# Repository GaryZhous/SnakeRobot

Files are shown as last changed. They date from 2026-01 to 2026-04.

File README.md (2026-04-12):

# 🐍 SnakeRobot

A snake robot built on the **ESP32** microcontroller. Eight servo motors create a sinusoidal traveling-wave gait, controlled via Bluetooth from a Python GUI that supports manual D-pad steering, autonomous direction tracking, and autonomous position control — with live telemetry (heading, X, Y) streamed back from an onboard IMU and optical-flow sensor.

Demo Video - [Google Drive Link](https://drive.google.com/file/d/18MDr4CC4aUVm_WDjIK8m0Mhruf4S-zMb/view?usp=sharing)

---

## Table of Contents
- [Design Fair Poster](#design-fair-poster)
- [Demo / Pinout](#demo--pinout)
- [How It Works](#how-it-works)
- [Hardware Setup](#hardware-setup)
- [Software Setup](#software-setup)
- [Bluetooth Commands](#bluetooth-commands)
- [Python GUI](#python-gui)
- [Camera Web Server](#camera-web-server)
- [3D Printing](#3d-printing)
- [Project Structure](#project-structure)

---

## Design Fair Poster

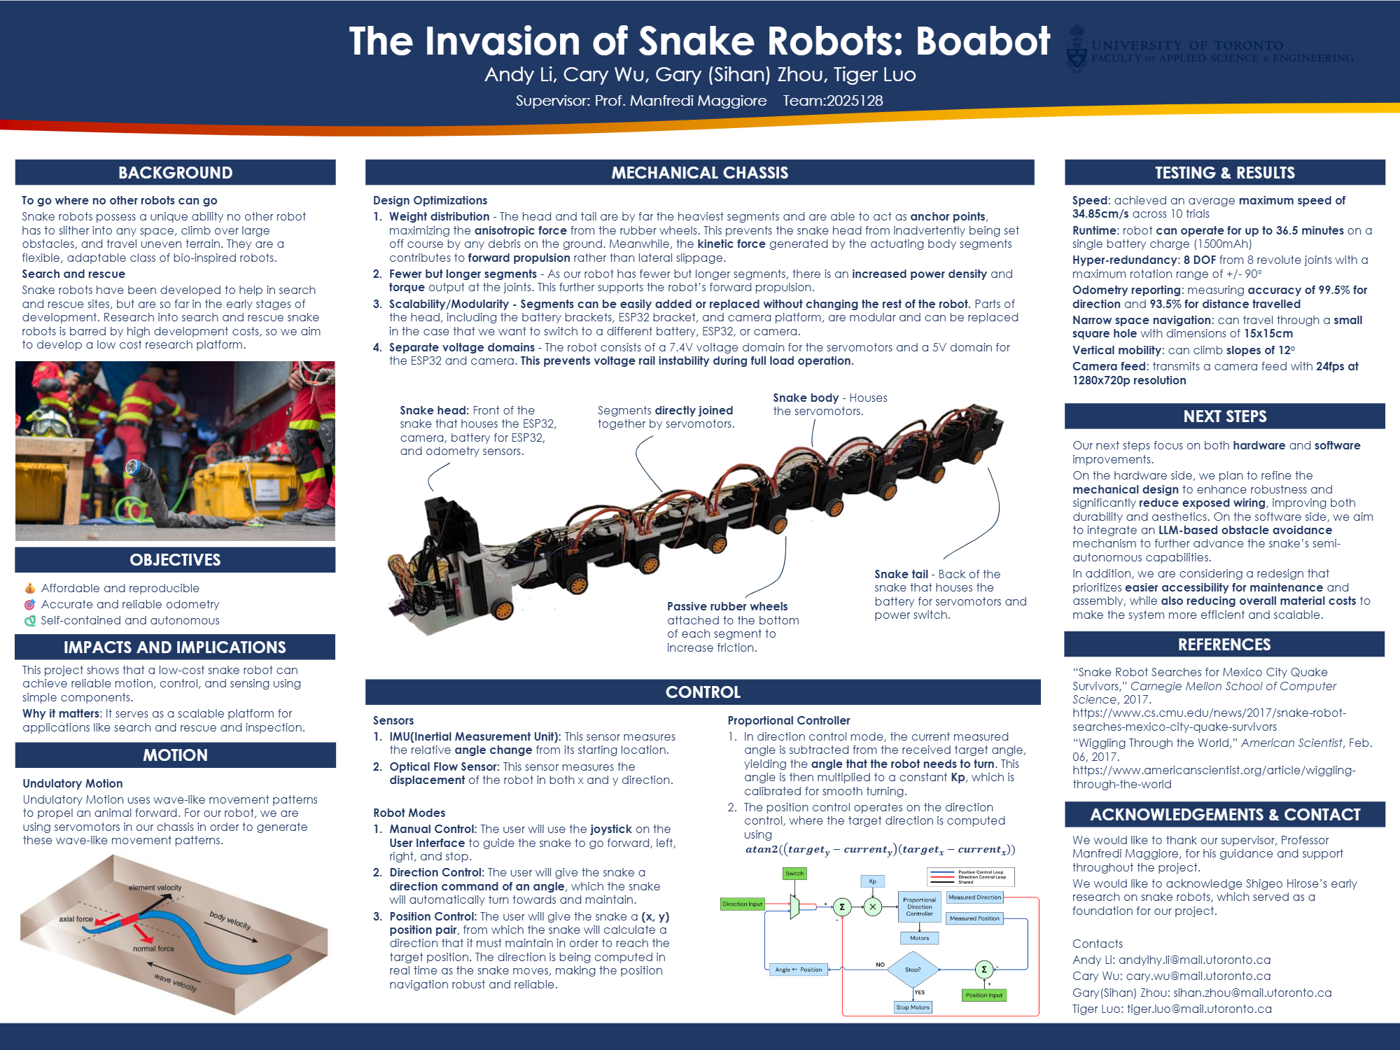
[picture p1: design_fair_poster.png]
Design Fair


The poster provides a high-level overview of the project — motivation, system architecture, hardware components, control strategy, and results — as presented at the UofT Electrical and Computer Engineering Undergraduate Capstone Design Fair on March 26, 2026.

---

## Demo / Pinout

ESP32 pinout reference

---

## How It Works

Each joint of the snake is driven by a servo. The firmware generates a **sinusoidal traveling wave** across all eight joints:

```
angle_i(t) = center + turnOffset + amplitude × sin(2π × frequency × t + i × 2π/8)
```

- **Frequency** is fixed at 0.5 Hz (one full undulation every 2 seconds).
- **Amplitude** (0 – 60 °) controls how wide each swing is — higher = faster forward motion.
- **Turn offset** shifts the neutral position of all joints together, steering the robot left or right.
- Both amplitude and turn offset are **slew-rate limited** so changes are smooth, not jerky.

The ESP32 reads heading from a **BNO08x IMU** and displacement from a **PMW3901 optical-flow sensor**, fusing them into world-frame odometry. This telemetry (heading, X position, Y position) is streamed back as packed `float32` frames so the Python GUI can display live position data and close a control loop.

---

## Hardware Setup

### Parts
| Qty | Component |
|-----|---|
| 1 | ESP32 development board |
| 8 | Servo motors (standard 5 V hobby servos) |
| 1 | BNO08x IMU (SPI) |
| 1 | Bitcraze PMW3901 optical-flow sensor (SPI) |
| 1 | 5 V regulated power supply (servos draw significant current) |
| — | Jumper wires, chassis / 3-D printed links (see [3D Printing](#3d-printing)) |

### Wiring

| Servo # | ESP32 GPIO |
|---|---|
| 1 | 13 |
| 2 | 12 |
| 3 | 14 |
| 4 | 27 |
| 5 | 26 |
| 6 | 25 |
| 7 | 33 |
| 8 | 32 |

| Sensor | Signal | ESP32 GPIO |
|---|---|---|
| BNO08x | CS | 15 |
| BNO08x | INT | 22 |
| BNO08x | RESET | 4 |
| PMW3901 | CS | 5 |
| Both | SCK / MISO / MOSI | 18 / 19 / 23 |

> **Tip:** Power the servos from a dedicated 5 V rail, **not** directly from the ESP32's 3.3 V pin. Share a common ground between the servo power supply and the ESP32.

### Motor Calibration
Before running the snake gait, make sure each servo is centered at 90 °:

1. Flash the `Calibration_Serial` sketch and open the Serial Monitor.
2. The sketch drives all servos to 90 ° sequentially so you can verify each joint.
3. Physically adjust the servo horns / linkages so the robot is straight.
4. Flash the main firmware and send `c` over Bluetooth to re-center before motion.

---

## Software Setup

### ESP32 Firmware

1. Install the **Arduino IDE** and add the ESP32 board package:  
   `https://raw.githubusercontent.com/espressif/arduino-esp32/gh-pages/package_esp32_index.json`
2. Install the following libraries via the Arduino Library Manager:
   - **ESP32Servo**
   - **Adafruit BNO08x** (IMU)
   - **Bitcraze PMW3901** (optical flow)
3. Open `ESP32/6_Position_Control_Avg_Yaw/` (the latest version) in the Arduino IDE, select your ESP32 board and COM port, then upload.

### Python GUI

Requires **Python 3.7+** and a Bluetooth-paired serial port.

```bash
pip install pyserial
# tkinter ships with most Python distributions; if missing:
# Ubuntu/Debian: sudo apt-get install python3-tk
# Windows/macOS: included in the standard Python installer
```

Pair your PC with the ESP32 Bluetooth device named **`ESP32_Snake`**, note the assigned COM port (e.g. `COM11` on Windows, `/dev/rfcomm0` on Linux), then edit the `PORT` constant at the top of `bluetooth.py`.

---

## Bluetooth Commands

All commands are sent as **exactly 8 ASCII bytes** over the Bluetooth SPP link (1 character header + 7 zero-padding bytes, e.g. `"l0000000"`).

### Mode markers
| Command | Action |
|---|---|
| `M0000000` | Switch to **Manual** mode |
| `D0000000` | Switch to **Direction** auto-control (tracks a target heading) |
| `P0000000` | Switch to **Position** auto-control (tracks target X/Y coordinates) |

### Motion commands (Manual mode)
| Key / Command | Action |
|---|---|
| `s` | Go **straight** — reset turn offset to 0 and resume motion |
| `l` | Turn **left** (smooth) |
| `r` | Turn **right** (smooth) |
| `c` | **Calibrate** — move all servos to 90 ° and stop motion |
| `0` – `9` | Set amplitude to `digit × 5` degrees (0 – 45 °) |
| `+` | Increase amplitude by 5 ° (up to 60 °) |
| `-` | Decrease amplitude by 5 ° |

### Auto-control payloads
| Format | Mode | Meaning |
|---|---|---|
| `+1200000` / `-0900000` | Direction | Target heading angle in degrees (signed, 8 chars) |
| `+100+200` | Position | Target X and Y position in cm (signed 3-digit each) |

---

## Python GUI

### `bluetooth.py` — Full Control Panel

- Connects to the ESP32 over a Bluetooth SPP serial port.
- Displays live **direction (°)**, **X position**, and **Y position** from the telemetry stream.
- **D-pad** for manual steering with drag support, auto-repeat, and analog angle input (−15 ° … +15 °).
- **Amplitude ±** buttons with a live display (range 0 – 60 °).
- **Mode selector** with three modes:
  - **Manual** — direct D-pad / key control.
  - **Direction** (auto) — enter a target heading; the robot steers to match it.
  - **Position** (auto) — enter target X/Y coordinates; the robot navigates to them.

**Running the script:**
```bash
python bluetooth.py
```

---

## Camera Web Server

The `CameraWebServer/` folder contains an **ESP32-CAM** sketch that streams live video over Wi-Fi.

### Setup
1. Open `CameraWebServer/CameraWebServer.ino` in the Arduino IDE.
2. Edit the `ssid` and `password` constants at the top of the file to match your Wi-Fi network.
3. Select the correct camera model by editing `board_config.h`.
4. Upload to an ESP32-CAM module.
5. Open the Serial Monitor at 115200 baud — after connecting the camera prints its local IP address.
6. Navigate to `http://<IP>` in a browser to view the live stream and camera controls.

---

## 3D Printing

The `CAD Files/` directory contains all STL meshes used to print the robot chassis, and the `3D Print Files/` directory contains pre-sliced Cura `.3mf` files ready to send directly to a printer.

### CAD Files (STL)

| File | Description |
|---|---|
| `Assembled.stl` | Full snake assembly reference |
| `AssembledHead.stl` / `AssembledTail.stl` | Head and tail sub-assemblies |
| `Head.stl` / `Tail.stl` | Individual head and tail prints |
| `Connecting Piece.stl` | Body links that join servo segments |
| `Motor Wrap.stl` | Servo motor sleeve / housing |
| `MG996R SBORKA.stl` | MG996R servo bracket assembly |
| `Clamp.stl` | Clamping ring for segment joints |
| `ESPBracket.stl` | ESP32 board mounting bracket |
| `ESP-WROOM32.stl` | ESP32 module reference model |
| `IMU.stl` | BNO08x IMU mounting housing |
| `Optical Flow Senssor.stl` | PMW3901 optical-flow sensor mount |
| `Battery.stl` / `BatteryBracket.stl` / `BatteryHead.stl` / `Battery Compartment.stl` | Battery enclosure and mounting hardware |
| `CamCaseTop.stl` / `CamCase Bottom.stl` | ESP32-CAM enclosure |
| `CameraPlatform 2.stl` | Camera platform for top-down mounting |

### 3D Print Files (pre-sliced)

Ready-to-print Cura `.3mf` files for **PLA** at standard settings:

| File | Contents |
|---|---|
| `Rev3 Segment.gcode.3mf` | Snake body link segments |
| `Rev3 Brackets PLA.gcode.3mf` | Servo mounting brackets |
| `Rev3 Head PLA.gcode.3mf` | Head section |
| `Rev3 Tail PLA.gcode.3mf` | Tail section |
| `Rev3 BatteryBracket PLA.gcode.3mf` | Battery bracket |
| `Rev3 CameraPlatform PLA.gcode.3mf` | Camera platform |
| `Servo Base Plate (1).gcode.3mf` | Servo base plate |

> **Tip:** Open `.3mf` files in [Ultimaker Cura](https://ultimaker.com/software/ultimaker-cura/) (or any slicer that supports `.3mf`) to preview or adjust print settings before slicing.

---

## Project Structure

```
SnakeRobot/
├── Team128_Design_Fair_Poster.pdf         # Design fair poster
├── Arduino/
│   └── Test_Code_250902/              # Early 2-servo Arduino prototype
├── CAD Files/                         # STL meshes for all printed parts
│   ├── Assembled.stl                  # Full snake assembly reference
│   ├── Head.stl / Tail.stl
│   ├── Connecting Piece.stl
│   ├── Motor Wrap.stl
│   ├── ESPBracket.stl
│   ├── IMU.stl / Optical Flow Senssor.stl
│   ├── Battery Compartment.stl / Battery.stl / ...
│   └── CamCaseTop.stl / CamCase Bottom.stl / ...
├── 3D Print Files/                    # Pre-sliced Cura .3mf files (PLA)
│   ├── Rev3 Segment.gcode.3mf
│   ├── Rev3 Brackets PLA.gcode.3mf
│   ├── Rev3 Head PLA.gcode.3mf
│   ├── Rev3 Tail PLA.gcode.3mf
│   ├── Rev3 BatteryBracket PLA.gcode.3mf
│   ├── Rev3 CameraPlatform PLA.gcode.3mf
│   └── Servo Base Plate (1).gcode.3mf
├── CameraWebServer/                   # ESP32-CAM Wi-Fi video stream server
│   ├── CameraWebServer.ino
│   ├── board_config.h
│   ├── camera_pins.h
│   └── ...
├── ESP32/
│   ├── Manual_Control_SerialBT/       # Basic manual Bluetooth control
│   ├── 1_Sensors_with_Manual_Control/
│   ├── 2_Sensors_with_Manual_Control_with_bluetooth_send_receive/
│   ├── 3_Proportional_control/        # Proportional steering controller
│   ├── 4_Analog_Manual/               # Analog angle steering via Bluetooth
│   ├── 5_Analog_Manual_Position_Control/  # Analog steering + position control
│   ├── 6_Position_Control_Avg_Yaw/    # ← Latest firmware (use this one)
│   ├── Calibration/                   # Servo calibration sketch
│   ├── Calibration_Serial/            # Serial-assisted servo calibration
│   ├── Tiger_avg_yaw/                 # Alternate position-control variant
│   ├── Test_Code_251028/
│   ├── Test_Code_251118.ino
│   ├── Test_Code_251130.cpp
│   ├── Test_Code_251202.cpp
│   ├── Test_Code_260109.cpp
│   ├── Test_Code_260114.cpp
│   ├── Test_Code_260119/              # Sensor integration test sketch
│   └── Test_Code_260119.cpp
├── bluetooth.py                       # Full-featured Python control GUI
└── README.md
```

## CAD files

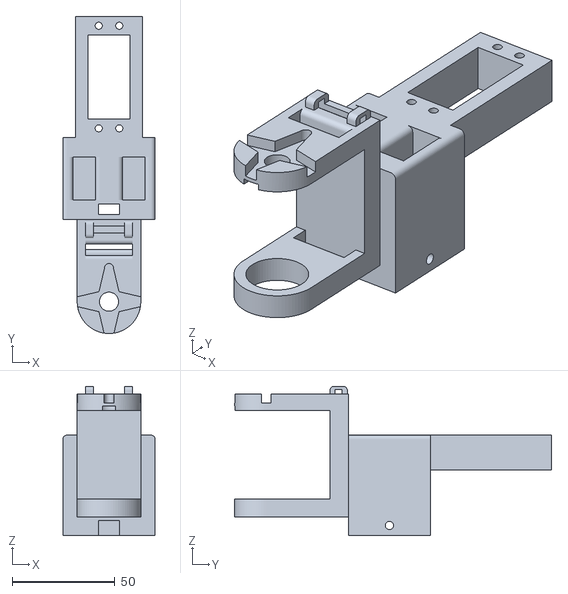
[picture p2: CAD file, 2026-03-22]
CAD Files/Assembled.stl
45.0 x 154.5 x 72.8

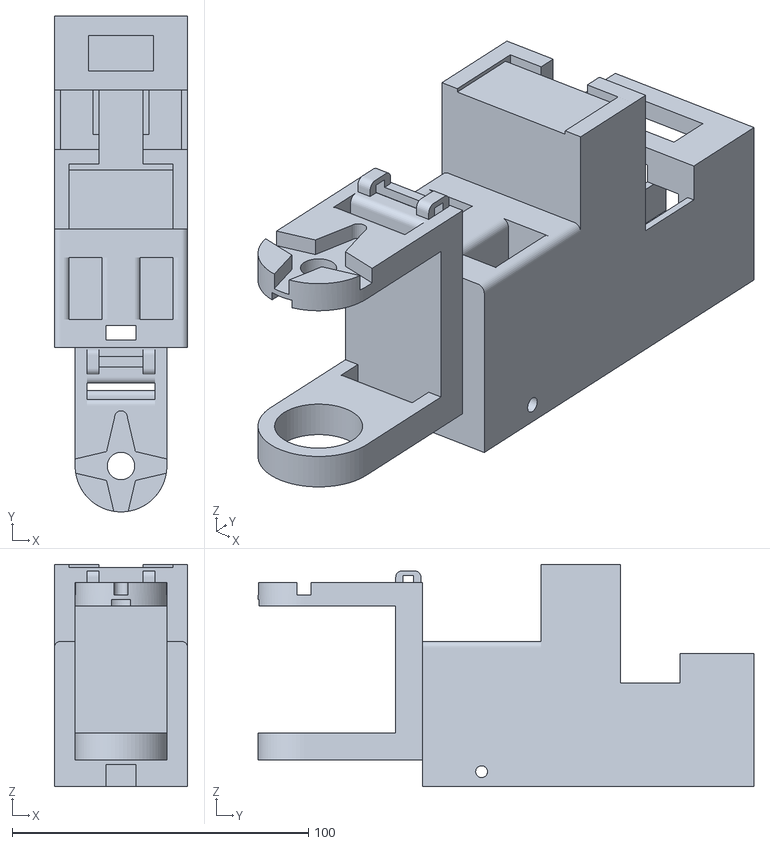
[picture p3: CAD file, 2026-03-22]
CAD Files/AssembledTail.stl
45.0 x 167.5 x 75.0

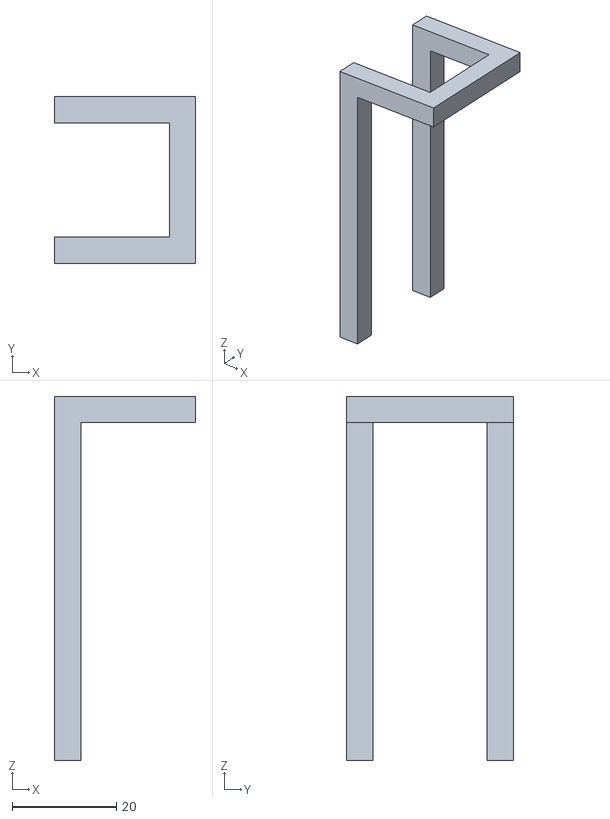
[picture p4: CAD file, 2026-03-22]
CAD Files/BatteryBracket.stl
27.1 x 32.1 x 70.0

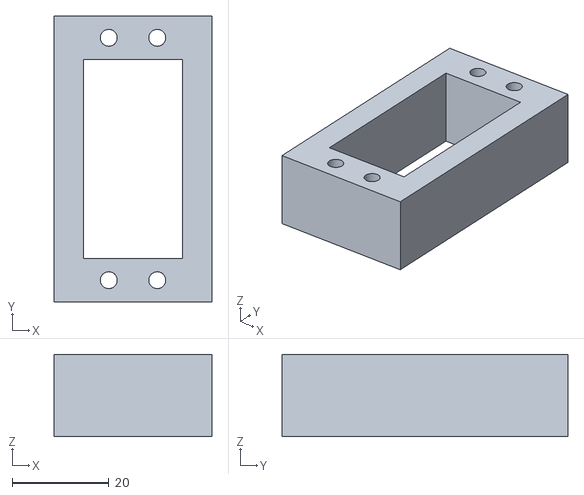
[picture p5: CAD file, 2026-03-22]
CAD Files/Motor Wrap.stl
32.5 x 59.0 x 17.0

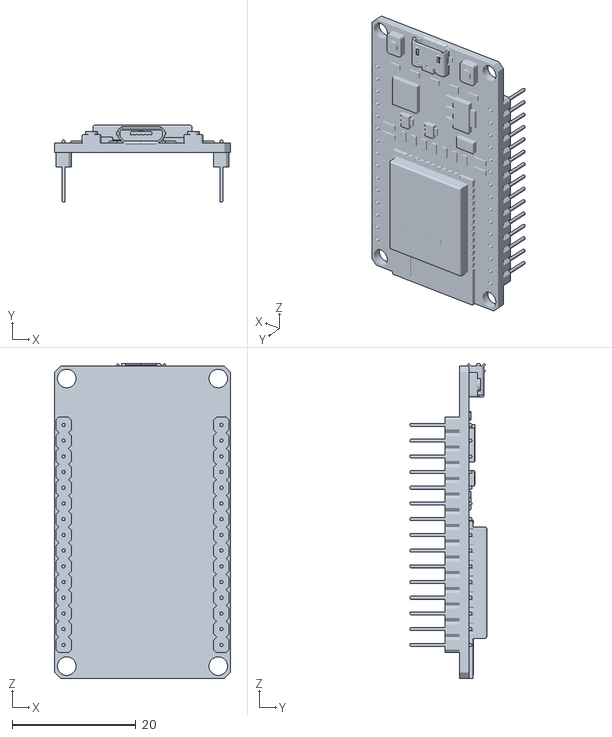
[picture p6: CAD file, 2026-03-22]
CAD Files/ESP-WROOM32.stl
28.5 x 12.4 x 50.9

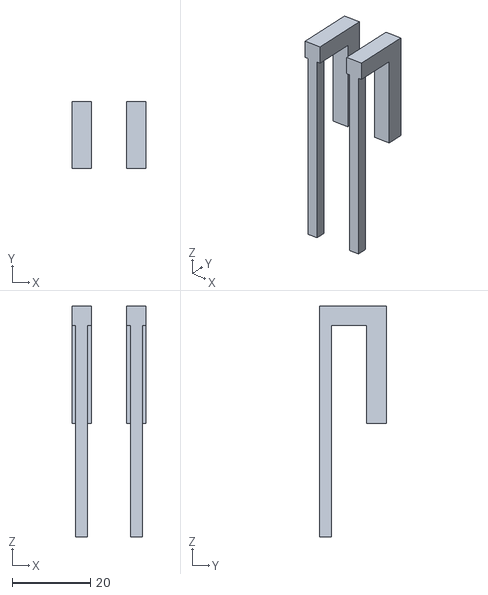
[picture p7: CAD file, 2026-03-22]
CAD Files/ESPBracket.stl
19.0 x 17.0 x 59.0

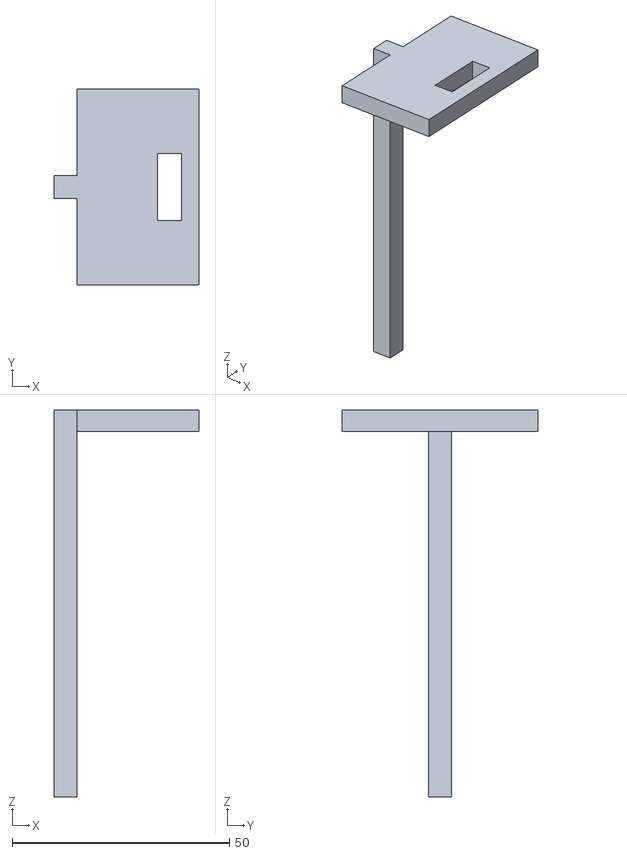
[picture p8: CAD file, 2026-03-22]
CAD Files/CameraPlatform 2.stl
33.3 x 45.0 x 89.0

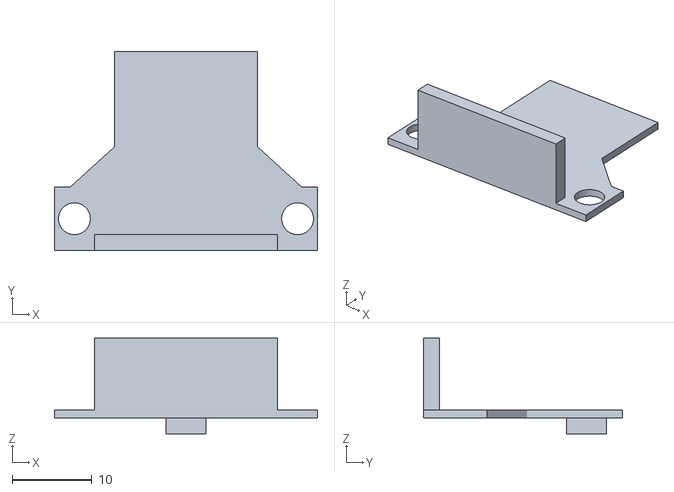
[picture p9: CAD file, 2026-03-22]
CAD Files/Optical Flow Senssor.stl
33.0 x 25.0 x 12.0

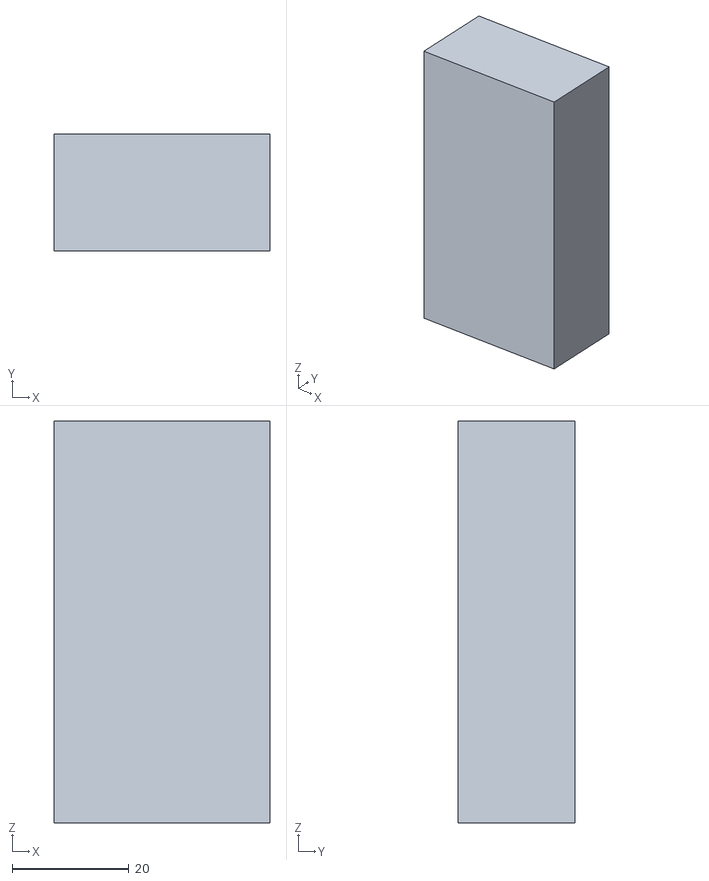
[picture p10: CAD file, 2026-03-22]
CAD Files/Battery.stl
37.0 x 20.0 x 69.0

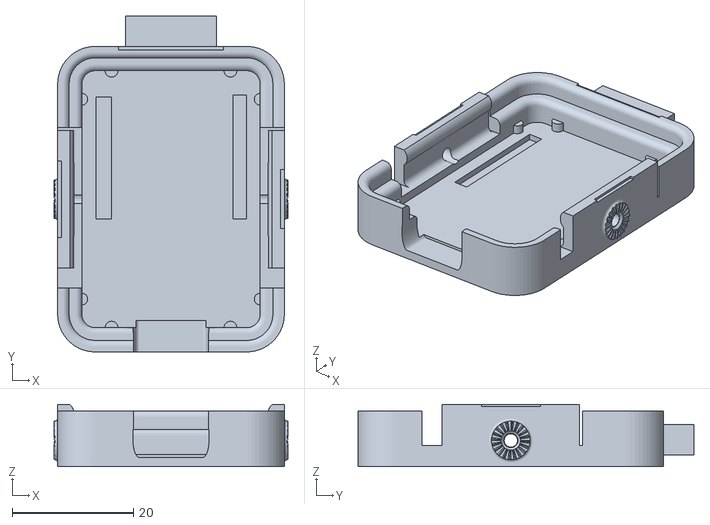
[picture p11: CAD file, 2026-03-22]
CAD Files/CamCase Bottom.stl
38.6 x 55.4 x 10.3

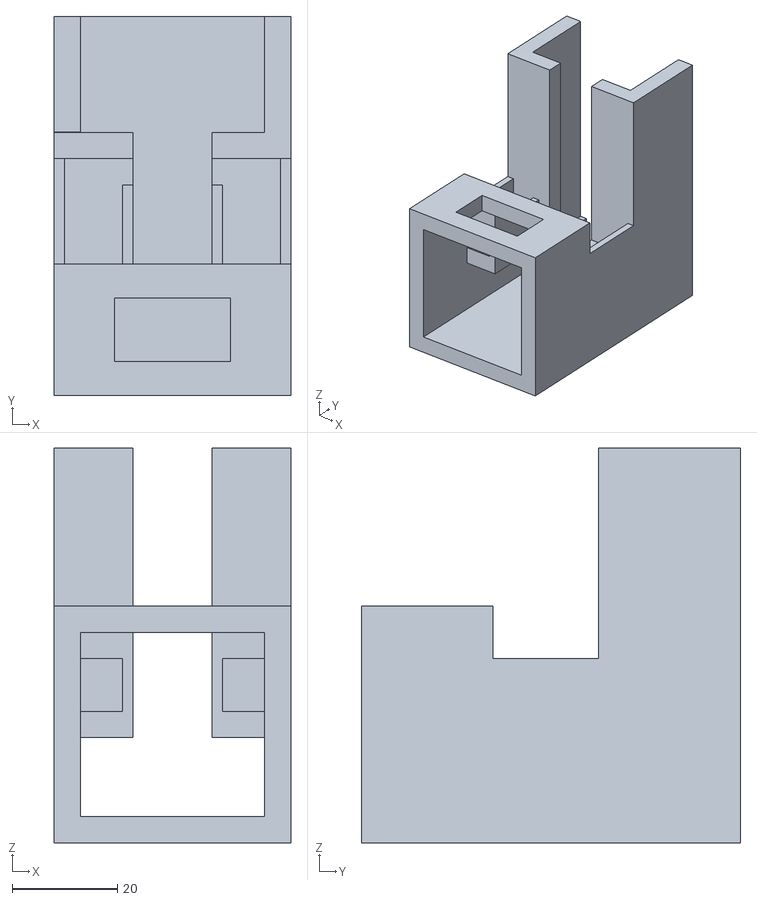
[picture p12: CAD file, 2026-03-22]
CAD Files/Battery Compartment.stl
45.0 x 72.0 x 75.0

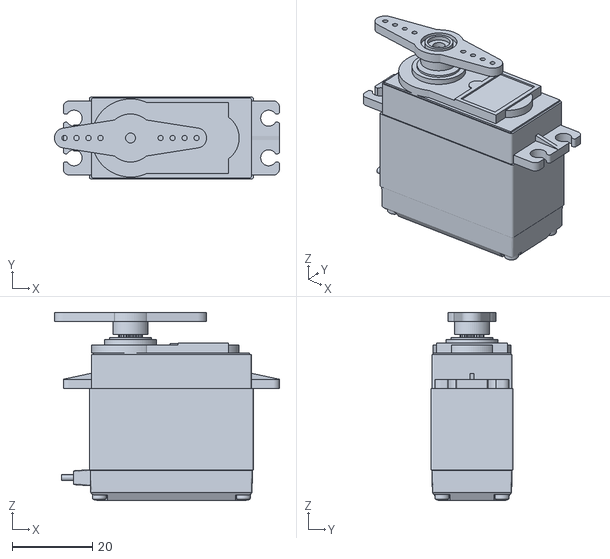
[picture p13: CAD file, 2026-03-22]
CAD Files/MG996R SBORKA.stl
56.2 x 20.5 x 47.0

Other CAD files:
3D Print Files/Rev3 Segment.gcode.3mf
3D Print Files/Rev3 Tail PLA.gcode.3mf
3D Print Files/Rev3 Brackets PLA.gcode.3mf
3D Print Files/Rev3 Head PLA.gcode.3mf
3D Print Files/Rev3 CameraPlatform PLA.gcode.3mf
3D Print Files/Rev3 BatteryBracket PLA.gcode.3mf
CAD Files/BatteryHead.stl
CAD Files/CamCaseTop.stl
CAD Files/Clamp.stl
CAD Files/Connecting Piece.stl
CAD Files/Head.stl
CAD Files/IMU.stl

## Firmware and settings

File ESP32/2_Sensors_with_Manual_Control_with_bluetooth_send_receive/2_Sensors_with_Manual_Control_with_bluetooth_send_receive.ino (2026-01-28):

/*
  ESP32 Snake Robot — Bluetooth SPP:
    - RX: single-byte commands from PC
    - TX: telemetry frames (12 bytes): <fff (dir_deg, x_m, y_m)

  IMPORTANT:
  - We ONLY print RX debug to USB Serial, NOT to Bluetooth,
    to avoid corrupting binary telemetry.
*/

#include <Arduino.h>
#include <SPI.h>
#include <math.h>

#include "BluetoothSerial.h"
#include "Bitcraze_PMW3901.h"
#include <Adafruit_BNO08x.h>

#include <ESP32Servo.h>

// =====================================================
// Pins
// =====================================================
// IMU (BNO08x) over SPI
#define BNO08X_CS    15
#define BNO08X_INT   22
#define BNO08X_RESET 4

// Optical flow (PMW3901) over SPI
#define FLOW_CS      5

// Shared SPI pins (ESP32 DOIT)
static const int PIN_SCK  = 18;
static const int PIN_MISO = 19;
static const int PIN_MOSI = 23;

// Servos
static const int   kNumServos = 5;
static const int   kServoPins[kNumServos] = {13, 12, 14, 27, 26};

// =====================================================
// Bluetooth
// =====================================================
static const char* kBtName = "ESP32_Snake";
BluetoothSerial SerialBT;

// =====================================================
// Sensors
// =====================================================
Bitcraze_PMW3901 flow(FLOW_CS);
Adafruit_BNO08x  bno08x(BNO08X_RESET);
sh2_SensorValue_t sensorValue;

static const sh2_SensorId_t kReportType = SH2_GAME_ROTATION_VECTOR;

// =====================================================
// Motion (servos)
// =====================================================
static const float kFrequencyHz = 0.5f;
static const float kCenterDeg   = 90.0f;
static const float kPhaseShift  = TWO_PI / kNumServos;

static const float kTurnSlewDegPerSec = 30.0f;
static const float kAmpSlewDegPerSec  = 60.0f;

static const float kAmpMin = 0.0f;
static const float kAmpMax = 60.0f;

static const float kTurnLeftOffsetDeg  = +15.0f;
static const float kTurnRightOffsetDeg = -15.0f;

static const int kUpdateDelayMs = 20;
static const int kServoMinUs = 500;
static const int kServoMaxUs = 2400;

Servo servos[kNumServos];

static bool  motionEnabled = false;
static float targetAmplitudeDeg  = 30.0f;
static float currentAmplitudeDeg = 30.0f;
static float targetTurnOffsetDeg  = 0.0f;
static float currentTurnOffsetDeg = 0.0f;

static unsigned long startTimeMs = 0;
static unsigned long lastLoopMs  = 0;

// =====================================================
// Position (world frame) + yaw handling
// =====================================================
static float xw_counts = 0.0f;
static float yw_counts = 0.0f;

static bool  yawInitialized = false;
static float yaw0_deg   = 0.0f;
static float lastYawDeg = 0.0f;
static float theta_deg  = 0.0f;
static float theta_rad  = 0.0f;

// Placeholder scale
// static const float meters_per_count = 1.0f / 60.0f;
static const float meters_per_count = 1.0f / 108.0f;

// =====================================================
// Telemetry timing
// =====================================================
static const uint32_t kTelemetryPeriodMs = 100; // 10 Hz
static uint32_t lastTelemetryMs = 0;

// =====================================================
// Helpers
// =====================================================
static inline float clampf(float x, float lo, float hi) {
  if (x < lo) return lo;
  if (x > hi) return hi;
  return x;
}

static inline float wrapDeg(float a) {
  while (a > 180.0f) a -= 360.0f;
  while (a < -180.0f) a += 360.0f;
  return a;
}

static inline float slewToward(float current, float target, float maxStep) {
  float diff = target - current;
  if (diff >  maxStep) diff =  maxStep;
  if (diff < -maxStep) diff = -maxStep;
  return current + diff;
}

static inline int clampAngleToServo(float deg) {
  deg = clampf(deg, 0.0f, 180.0f);
  return (int)(deg + 0.5f);
}

static void calibrateToCenter() {
  for (int i = 0; i < kNumServos; i++) {
    servos[i].write((int)kCenterDeg);
  }
}

// Write one float32 to BT as 4 bytes (little-endian)
static void writeFloatLE(BluetoothSerial& bt, float v) {
  uint8_t b[4];
  memcpy(b, &v, 4);
  bt.write(b, 4);
}

static void setReports() {
  if (!bno08x.enableReport(kReportType)) {
    Serial.println("BNO08x: Could not enable GAME ROTATION VECTOR");
  }
}

// Yaw from GAME rotation vector quaternion
static float yawFromGameQuatDeg(const sh2_SensorValue_t& sv) {
  const float qr = sv.un.gameRotationVector.real;
  const float qi = sv.un.gameRotationVector.i;
  const float qj = sv.un.gameRotationVector.j;
  const float qk = sv.un.gameRotationVector.k;

  const float sqr = qr*qr, sqi = qi*qi, sqj = qj*qj, sqk = qk*qk;
  float yaw = atan2f(2.0f * (qi*qj + qk*qr), (sqi - sqj - sqk + sqr));
  return yaw * (180.0f / PI);
}

// =====================================================
// Bluetooth RX (control) + DEBUG PRINT (USB Serial)
// =====================================================
static void processCommand(char c) {
  if (c == 'c' || c == 'C') {
    targetTurnOffsetDeg  = 0.0f;
    currentTurnOffsetDeg = 0.0f;
    //targetAmplitudeDeg   = 0.0f;
    //currentAmplitudeDeg  = 0.0f;
    calibrateToCenter();
    motionEnabled = false;

  } else if (c == 'l' || c == 'L') {
    targetTurnOffsetDeg = kTurnLeftOffsetDeg;

  } else if (c == 'r' || c == 'R') {
    targetTurnOffsetDeg = kTurnRightOffsetDeg;

  } else if (c == 's' || c == 'S') {
    targetTurnOffsetDeg = 0.0f;
    motionEnabled = true;

  } else if (c >= '0' && c <= '9') {
    int d = c - '0';
    targetAmplitudeDeg = clampf(d * 5.0f, kAmpMin, kAmpMax);

  } else if (c == '+') {
    targetAmplitudeDeg = clampf(targetAmplitudeDeg + 5.0f, kAmpMin, kAmpMax);

  } else if (c == '-') {
    targetAmplitudeDeg = clampf(targetAmplitudeDeg - 5.0f, kAmpMin, kAmpMax);
  }
}

static void handleBluetoothRx() {
  while (SerialBT.available() > 0) {
    char c = (char)SerialBT.read();      // 1 byte
    Serial.print("RX: '");               // DEBUG to USB serial
    Serial.print(c);
    Serial.println("'");

    processCommand(c);
  }
}

// =====================================================
// Sensors + position update
// =====================================================
static void updateSensorsAndPosition() {
  int16_t dx = 0, dy = 0;
  flow.readMotionCount(&dx, &dy);

  if (bno08x.wasReset()) {
    setReports();
  }

  if (bno08x.getSensorEvent(&sensorValue)) {
    if (sensorValue.sensorId == kReportType) {
      float yawDeg = yawFromGameQuatDeg(sensorValue);
      lastYawDeg = yawDeg;

      if (!yawInitialized) {
        yaw0_deg = lastYawDeg;
        yawInitialized = true;
      }
    }
  }

  if (!yawInitialized) return;

  theta_deg = wrapDeg(lastYawDeg - yaw0_deg);
  theta_rad = theta_deg * (PI / 180.0f);

  const float c = cosf(theta_rad);
  const float s = sinf(theta_rad);

  const float dXw = c * (float)dx - s * (float)dy;
  const float dYw = s * (float)dx + c * (float)dy;

  xw_counts += dXw;
  yw_counts += dYw;
}

// =====================================================
// Motion update (servos)
// =====================================================
static void updateMotion(float dtSec, unsigned long nowMs) {
  const float maxTurnStep = kTurnSlewDegPerSec * dtSec;
  const float maxAmpStep  = kAmpSlewDegPerSec  * dtSec;

  currentTurnOffsetDeg = slewToward(currentTurnOffsetDeg, targetTurnOffsetDeg, maxTurnStep);
  currentAmplitudeDeg  = slewToward(currentAmplitudeDeg,  targetAmplitudeDeg,  maxAmpStep);

  const float tSec  = (nowMs - startTimeMs) / 1000.0f;
  const float omega = TWO_PI * kFrequencyHz;

  for (int i = 0; i < kNumServos; i++) {
    const float phase = i * kPhaseShift;
    const float angle = (kCenterDeg + currentTurnOffsetDeg)
                      + currentAmplitudeDeg * sinf(omega * tSec + phase);

    servos[i].write(clampAngleToServo(angle));
  }
}

// =====================================================
// Telemetry TX (12 bytes total): direction + x + y
// =====================================================
static void sendTelemetry12B() {
  if (!SerialBT.hasClient()) return;
  if (!yawInitialized) return;

  const float xw_m = xw_counts * meters_per_count;
  const float yw_m = yw_counts * meters_per_count;
  const float direction_deg = theta_deg;

  writeFloatLE(SerialBT, direction_deg);
  writeFloatLE(SerialBT, xw_m);
  writeFloatLE(SerialBT, yw_m);
}

// =====================================================
// Setup / Loop
// =====================================================
void setup() {
  Serial.begin(115200);
  delay(200);

  SPI.begin(PIN_SCK, PIN_MISO, PIN_MOSI);

  pinMode(FLOW_CS, OUTPUT);
  pinMode(BNO08X_CS, OUTPUT);
  digitalWrite(FLOW_CS, HIGH);
  digitalWrite(BNO08X_CS, HIGH);
  delay(50);

  // ---- Init PMW3901 ----
  if (!flow.begin()) {
    Serial.println("PMW3901 init FAILED");
    while (1) delay(100);
  }
  Serial.println("PMW3901 init OK");

  // ---- Init BNO08x over SPI ----
  if (!bno08x.begin_SPI(BNO08X_CS, BNO08X_INT)) {
    Serial.println("BNO08x init FAILED");
    while (1) delay(100);
  }
  Serial.println("BNO08x init OK");
  setReports();

  // ---- Bluetooth ----
  if (!SerialBT.begin(kBtName)) {
    Serial.println("Bluetooth failed to start!");
  } else {
    Serial.print("Bluetooth started. Pair to: ");
    Serial.println(kBtName);
  }

  // ---- Servos ----
  ESP32PWM::allocateTimer(0);
  ESP32PWM::allocateTimer(1);
  ESP32PWM::allocateTimer(2);
  ESP32PWM::allocateTimer(3);

  for (int i = 0; i < kNumServos; i++) {
    servos[i].setPeriodHertz(50);
    servos[i].attach(kServoPins[i], kServoMinUs, kServoMaxUs);
  }

  calibrateToCenter();

  startTimeMs = millis();
  lastLoopMs  = startTimeMs;
  lastTelemetryMs = startTimeMs;

  Serial.println("Ready.");
  Serial.println("Commands over BT: c l r s 0..9 + -");
  Serial.println("Telemetry over BT: 12 bytes/frame (dir_deg, xw_m, yw_m) float32 LE");
}

void loop() {
  handleBluetoothRx();          // RX control + print RX byte to USB Serial
  updateSensorsAndPosition();   // integrate position

  const unsigned long nowMs = millis();
  const float dtSec = (nowMs - lastLoopMs) / 1000.0f;
  lastLoopMs = nowMs;

  if (motionEnabled) {
    updateMotion(dtSec, nowMs);
  }

  if (nowMs - lastTelemetryMs >= kTelemetryPeriodMs) {
    lastTelemetryMs = nowMs;
    sendTelemetry12B();         // TX telemetry (12 bytes)
  }

  delay(kUpdateDelayMs);
}

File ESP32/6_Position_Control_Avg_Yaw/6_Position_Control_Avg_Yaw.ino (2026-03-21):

/*
  ESP32 Snake Robot — Bluetooth SPP (Strict 8-Byte Protocol)
  - RX: Exactly 8 bytes per packet.
  - TX: 12-byte telemetry frames (dir, x, y) float32 LE.
*/

#include <Arduino.h>
#include <SPI.h>
#include <math.h>
#include "BluetoothSerial.h"
#include "Bitcraze_PMW3901.h"
#include <Adafruit_BNO08x.h>
#include <ESP32Servo.h>

// =====================================================
// Pins & Constants
// =====================================================
#define BNO08X_CS    15
#define BNO08X_INT   22
#define BNO08X_RESET  4
#define FLOW_CS       5
#define FLOW_RST      21

static const int kNumServos = 8;
static const int kServoPins[kNumServos] = {13, 12, 14, 27, 26, 25, 33, 32};
static const float centimeters_per_count_y = 1.0f / 110.0f; // from 1/108
static const float centimeters_per_count_x = 1.0f / 135.0f; // from 1/108

// --- Control Modes & Gains ---
enum ControlMode { MODE_M, MODE_P, MODE_D };
ControlMode currentMode = MODE_M;

static int autoTargetYaw = 0; 
static const float Kp_yaw = 0.2f;        
static const float kMaxAutoTurn = 15.0f; 

static const char* kBtName = "ESP32_Snake";
BluetoothSerial SerialBT;

Bitcraze_PMW3901 flow(FLOW_CS);
Adafruit_BNO08x  bno08x(BNO08X_RESET);
sh2_SensorValue_t sensorValue;

// Motion State
static bool motionEnabled = false;
static float targetAmplitudeDeg = 30.0f;
static float currentAmplitudeDeg = 25.0f; // from 30
static float targetTurnOffsetDeg = 0.0f;
static float currentTurnOffsetDeg = 0.0f;


// Odometry
static float xw_counts = 0.0f;
static float yw_counts = 0.0f;
static bool  yawInitialized = false;
static float yaw0_deg = 0.0f;
static float lastYawDeg = 0.0f;
static float theta_deg = 0.0f;

static unsigned long startTimeMs = 0;
static unsigned long lastLoopMs = 0;
static uint32_t lastTelemetryMs = 0;
static const uint32_t kTelemetryPeriodMs = 100;

// Position Targets
static float targetX_cm = 0.0f; // Target X in meters
static float targetY_cm = 0.0f; // Target Y in meters

Servo servos[kNumServos];

//Global declarations for averaged yaw
const int max_samples = 20;
const float period = 1000/0.5f; //In ms
const float sampling_period = 2000/max_samples;
unsigned long prev_sample_time = 0;
int sample_idx = 0;
float yaw_samples [max_samples] = {0};
float x_samples [max_samples] = {0};
float y_samples [max_samples] = {0};
float sum_x;
float sum_y;
float avg_yaw = 0;

// =====================================================
// Helpers
// =====================================================
static inline float clampf(float x, float lo, float hi) { return (x < lo) ? lo : (x > hi) ? hi : x; }
static inline float wrapDeg(float a) { while (a > 180.0f) a -= 360.0f; while (a < -180.0f) a += 360.0f; return a; }

static inline float slewToward(float current, float target, float maxStep) {
    float diff = target - current;
    if (diff > maxStep) diff = maxStep;
    if (diff < -maxStep) diff = -maxStep;
    return current + diff;
}

void calibrateToCenter() {
    //for (int i = 0; i < kNumServos; i++) servos[i].write(90);
    for (int i = (kNumServos/2)-1; i >= 0; i--) {
        servos[i].write(90);
        servos[(kNumServos-1)-i].write(90);
    }
}

void writeFloatLE(BluetoothSerial& bt, float v) {
    uint8_t b[4];
    memcpy(b, &v, 4);
    bt.write(b, 4);
}

float update_average(float yaw){ //Give it a clamped yaw IN RADIANS
    unsigned long cur_sample_time = millis();
    if (cur_sample_time-prev_sample_time>sampling_period){
        

        yaw_samples[sample_idx%max_samples] = yaw;
        sum_x=0;
        sum_y=0;
        for (int i=0; i<max_samples; i++){
            sum_x += cos(yaw_samples[i]);
            sum_y += sin(yaw_samples[i]);
        }

        avg_yaw = atan2(sum_y, sum_x);
        sample_idx++;
    }
    return avg_yaw;
}

void processManualCommand(char c, uint8_t packet[8]) {
    c = tolower(c);
    if (c == 'c') {
        targetTurnOffsetDeg = 0.0f;
        currentTurnOffsetDeg = 0.0f;
        calibrateToCenter();
        motionEnabled = false;
        Serial.println("Mode M: CENTER & STOP");
    } else if (c == '+') {
        targetAmplitudeDeg = clampf(targetAmplitudeDeg + 5.0f, 0.0f, 60.0f);
    } else if (c == '-') {
        targetAmplitudeDeg = clampf(targetAmplitudeDeg - 5.0f, 0.0f, 60.0f);
    } else if (c != 'D' && c != 'P' && c != 'M' && c != 'c'){

        motionEnabled = true;
        int manual_angle = 0;

        manual_angle += (packet[1] - '0') * 100;
        manual_angle += (packet[2] - '0') * 10;
        manual_angle += (packet[3] - '0');

        manual_angle -= 90;

        targetTurnOffsetDeg = (float) manual_angle;

        Serial.println("Mode M: angle received:");
        Serial.println(manual_angle);
        Serial.println();
    }
}
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

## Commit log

2025-11-20 Implement motor calibration function
    Added a calibrate function to align motors when called.
2025-11-30 Add servo control code for ESP32
2025-12-03 Clarify MAC address comment for ESP32
    Updated comment to clarify MAC address usage.
2025-12-08 Document pins used for motors in README
    Added information about pins used for motors.
2026-01-10 Add ESP32 servo control with Bluetooth support
2026-01-10 Update README with motor calibration instruction
    Added a note to calibrate the motors using Python code.
2026-01-14 Implement GUI for ESP32 Bluetooth Controller
    Refactor ESP32 Bluetooth controller to use a GUI with Tkinter. Added connection management, command sending, and logging features.
2026-01-14 Change default ESP32 address in bluetooth.py
2026-01-19 Add ESP32 servo control with Bluetooth integration
2026-01-20 Added IMU and Flow Sensor Test Code
2026-01-23 Integrated Sensors with control
2026-01-23 Update motor pin order in README
    Reordered motor pin configuration for clarity.
2026-01-23 Working Sensor + bluetooth
2026-02-10 Fix main function call formatting
    [bluetooth.py]
2026-03-08 Revert bluetooth_receive.py — no changes needed in that file
2026-03-11 Implement manual analog steering and update UI
    Added manual analog steering functionality with angle control and updated D-pad frame text.
2026-03-16 0316 Added 3 extra motors
2026-03-17 Fix servo values in the README
    Updated servo values in the README to reflect correct data.
2026-03-17 Invert angle direction for manual angle adjustments
    [bluetooth.py]
2026-03-18 Fixed average yaw
2026-03-19 Working proportional, added camera code
    [partitions.csv]
2026-03-20 Add Stop button and stop command functionality
    Added a Stop button to the control mode interface and implemented the _send_stop method to handle stop commands.
2026-03-22 Adding CAD and 3D print files
    [Assembled.stl, AssembledTail.stl, Battery Compartment.stl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]
2026-03-22 Update README to document CAD Files and 3D Print Files directories
    Agent-Logs-Url: https://github.com/GaryZhous/SnakeRobot/sessions/81068629-520e-4f99-a6c4-39ec08ead1ac
